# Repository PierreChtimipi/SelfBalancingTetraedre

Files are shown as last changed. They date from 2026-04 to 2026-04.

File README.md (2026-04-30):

# SelfBalancingTetraedre — Robot TétraCubli

Projet de robot auto-équilibrant en forme de tétraèdre de Reuleaux. Le robot repose sur une face, puis utilise l'élan gyroscopique d'une roue de réaction entraînée par un moteur brushless pour se redresser et maintenir sa position verticale en équilibre instable. Le projet regroupe le firmware embarqué (ESP32), des simulations MATLAB pour valider les lois de commande, et des modèles 3D pour la mécanique.

---

## Table des matières

1. [Architecture générale](#architecture-générale)
2. [Matériel utilisé](#matériel-utilisé)
3. [Configuration du projet](#configuration-du-projet)
4. [Code source (`src/`)](#code-source-src)
5. [Simulations MATLAB (`Simu_Matlab/`)](#simulations-matlab-simu_matlab)
6. [Modèles 3D (`modelisation3D/`)](#modèles-3d-modelisation3d)
7. [Configuration VSCode (`.vscode/`)](#configuration-vscode-vscode)
8. [Dépendances (`ESP32Servo`)](#dépendances-esp32servo)
9. [Artefacts de compilation (`.pio/`)](#artefacts-de-compilation-pio)

---

## Architecture générale

```
SelfBalancingTetraedre/
├── src/                    # Code source embarqué (C++)
│   ├── main.cpp
│   ├── Theorie_Proto1FaceBNO.cpp
│   ├── testCapteur.cpp
│   ├── testMoteur.cpp
│   └── testled.cpp
├── Simu_Matlab/            # Simulations de la dynamique (MATLAB)
│   ├── 2D/
│   │   ├── nominale2D.m
│   │   └── redressement2D.m
│   └── 3D/
│       ├── nominale3D.m
│       ├── redressement3D.m
│       ├── exp3.m
│       └── solution.m
├── modelisation3D/         # Fichiers de conception mécanique
│   ├── Cubli 3D.f3d
│   ├── Support moteur.3mf
│   └── Tétracubli.3mf
├── include/                # Fichiers d'en-tête partagés
├── lib/                    # Bibliothèques privées du projet
├── .vscode/                # Configuration de l'éditeur
├── platformio.ini          # Configuration de compilation PlatformIO
└── .gitignore
```

---

## Matériel utilisé

| Composant | Rôle |
|---|---|
| **ESP32** | Microcontrôleur principal (240 MHz, dual-core) |
| **MPU-6500 / MPU-9250** | IMU 6/9 axes (accéléromètre + gyroscope) via I2C |
| **BNO055** | IMU 9 axes avec fusion capteur intégrée (implémentation alternative) |
| **ESC (Electronic Speed Controller)** | Contrôleur de vitesse pour moteur brushless, commande PWM |
| **Moteur brushless** | Entraîne la roue de réaction pour le contrôle gyroscopique |
| **LEDs (GPIO 2, 4, 5)** | Indicateurs de diagnostic |

---

## Configuration du projet

### `platformio.ini`

Fichier de configuration central de PlatformIO qui définit l'environnement de compilation et de téléversement.

- **Plateforme** : `espressif32` — outillage pour microcontrôleurs Espressif ESP32
- **Carte** : `esp32doit-devkit-v1` — variante spécifique avec ses configurations de broches
- **Framework** : `arduino` — permet d'utiliser les API Arduino sur l'ESP32
- **Vitesse du moniteur série** : 115 200 bauds, standard pour la communication de débogage
- **Filtre de compilation** : seul `src/main.cpp` est compilé, pour éviter de compiler les fichiers de test lors du déploiement
- **Dépendance** : `madhephaestus/ESP32Servo @ ^3.0.5`, bibliothèque de contrôle PWM pour servos et ESC

### `.gitignore`

Exclut du suivi Git les fichiers générés automatiquement :
- Le dossier `.pio/` contenant les binaires compilés, fichiers objets et firmwares — inutile à versionner
- Les fichiers de cache IntelliSense et les configurations auto-générées de VSCode (`.vscode/c_cpp_properties.json`, `.vscode/launch.json`, `.vscode/ipch`) pour éviter des conflits entre développeurs

---

## Code source (`src/`)

### `main.cpp` — Contrôleur principal d'équilibre

Programme de production qui implémente la logique complète de redressement et d'équilibrage via une machine à états.

**Capteurs et actionneurs :**
- IMU **MPU-6500** (I2C sur GPIO 21/22 à 400 kHz) pour estimer l'angle et la vitesse angulaire
- **ESC** sur GPIO 18, commandé en PWM à 250 Hz (impulsions entre 1 000 µs et 2 000 µs)

**Algorithmes clés :**

1. **Calibration du gyroscope** : au démarrage, 200 lectures à l'arrêt permettent d'estimer le biais du gyroscope, soustrait ensuite à chaque mesure pour limiter la dérive.

2. **Calibration de la verticale** : l'utilisateur maintient le robot vertical pendant 2 secondes ; la moyenne de 50 mesures définit l'angle de référence `vertical_zero_offset_rad`.

3. **Filtre complémentaire** : fusionne les données accéléromètre (stabilité long-terme) et gyroscope (réactivité court-terme) avec un coefficient `alpha = 0.96` pour estimer l'angle `theta` en temps réel.

4. **Machine à états en 4 phases** :
   - `STATE_LYING_FLAT` : le robot est couché. Il attend que l'angle dépasse 30° puis déclenche la montée en vitesse.
   - `STATE_SPIN_UP` : montée en régime progressive sur 1,5 s, de 1 000 µs à 1 800 µs, pour accumuler l'élan gyroscopique sans à-coups.
   - `STATE_IMPULSE` : coupure instantanée de la commande moteur (1 000 µs), permettant au momentum accumulé de faire basculer le robot vers la verticale. Dure 200 ms ou jusqu'à ce que l'angle passe sous 25°.
   - `STATE_BALANCING` : équilibre actif par régulateur PD+W.

5. **Régulateur PD avec compensation de vitesse roue (PD+W)** :
   - Loi de commande : `τ = -Kp·θ - Kd·θ̇ - Kw·ω_w`
   - `Kp = 0.74` (action proportionnelle à l'angle), `Kd = 0.06` (amortissement), `Kw = 0.005` (compensation de la vitesse roue)
   - La vitesse de la roue `ω_w` est estimée par simulation (encodeur virtuel) puisqu'aucun encodeur physique n'est disponible

6. **Conversion couple → commande PWM** : le couple commandé est converti en courant via la constante moteur `Kt = 0.0095`, saturé à ±12 A, puis mappé en microsecondes pour l'ESC.

**Fréquences d'exécution** : estimation IMU à 200 Hz, boucle de commande à 100 Hz, affichage série à 10 Hz.

---

### `Theorie_Proto1FaceBNO.cpp` — Implémentation alternative avec BNO055

Implémentation alternative utilisant l'IMU **BNO055** d'Adafruit à la place du MPU-6500. Le BNO055 intègre un filtre de Kalman matériel et retourne directement des angles d'Euler fusionnés, simplifiant considérablement le code.

**Différences clés par rapport à `main.cpp` :**
- Pas de filtre complémentaire manuel : le capteur gère lui-même la fusion
- Filtre passe-bas exponentiel appliqué à l'angle de tangage (`alpha = 0.85`)
- Régulateur PD simplifié : `correction = Kp·(pitch_cible - pitch_filtré) - Kd·gyro_z` avec `Kp = 12.0`, `Kd = 5.0`
- Boucle de commande à 200 Hz, correction saturée à ±300 µs autour du point neutre 1 500 µs
- Protection contre les mesures invalides (NaN) : coupure immédiate du moteur si détectée
- ESC sur GPIO 18 à 50 Hz (au lieu de 250 Hz dans `main.cpp`)

Ce fichier représente une voie d'exploration avec un capteur plus intégré, permettant de valider si la fusion matérielle du BNO055 apporte un avantage par rapport à la fusion logicielle du MPU.

---

### `testCapteur.cpp` — Test et validation de l'IMU MPU-9250

Programme de diagnostic permettant de valider le bon fonctionnement de l'IMU et d'explorer les techniques de fusion de capteurs avant de les intégrer au contrôleur principal.

**Fonctionnement :**
- Lit le registre `WHO_AM_I` (0x75) pour identifier le capteur (codes acceptés : 0x71, 0x73, 0x70)
- Effectue une calibration sur 500 échantillons à l'arrêt, en soustrayant 1g sur l'axe Z pour isoler le biais réel
- Applique un filtre complémentaire (alpha = 0.98) pour produire des angles `angle_x` et `angle_y` stables
- Convertit les valeurs brutes 16 bits en unités physiques : accélération en g (÷ 16 384), vitesse angulaire en °/s (÷ 65,5)
- Affiche les données à 10 Hz sur la liaison série

Utile en phase de développement pour vérifier l'orientation du capteur, la qualité du signal, et régler les paramètres de filtrage avant de les transposer dans le contrôleur.

---

### `testMoteur.cpp` — Test et mise en service de l'ESC

Programme de mise en service permettant de vérifier le bon fonctionnement de l'ESC et du moteur brushless, et d'armer l'ESC de manière sécurisée.

**Séquence exécutée :**
1. Allocation des 4 timers matériels PWM de l'ESP32 via la bibliothèque ESP32PWM
2. Envoi de la commande minimale (1 000 µs) pendant 7 secondes pour l'armement de l'ESC — l'utilisateur peut connecter la batterie en toute sécurité pendant ce délai
3. Montée progressive de 1 000 µs à 1 200 µs par incréments de 5 µs toutes les 20 ms (rampe de 4 s)
4. Maintien à 1 200 µs pendant 1 s
5. Descente progressive de 1 200 µs à 1 000 µs au même rythme
6. Pause de 2 s puis répétition du cycle

Ce fichier est exclusivement un outil de développement/commission, pas une partie du firmware de production.

---

### `testled.cpp` — Test des sorties GPIO

Utilitaire minimal de validation des broches GPIO connectées à des LEDs (GPIO 2, 4, 5).

Pour chaque broche, le programme effectue alternativement des tests en logique active-haute (HIGH = LED allumée) et active-basse (LOW = LED allumée), à raison de 4 basculements de 400 ms chacun. Cela permet de vérifier les deux configurations de câblage (alimentation commune vs masse commune) et de s'assurer que le microcontrôleur contrôle bien ses sorties numériques.

---

## Simulations MATLAB (`Simu_Matlab/`)

Les simulations modélisent le tétraèdre de Reuleaux comme un **pendule inversé** et valident la faisabilité du contrôle avant implémentation matérielle. Toutes utilisent l'intégration numérique d'Euler à pas de 5 ms.

### `2D/nominale2D.m` — Stabilisation nominale 2D

Modélise une face unique du tétraèdre traitée comme un pendule inversé 2D. Paramètres : masse 0,25 kg, bras de levier 50 mm, inertie 0,003 kg·m².

Valide que le régulateur **PID** (Kp = 7, Ki = 0,3, Kd = 1,8) avec saturation du couple à ±0,08 N·m stabilise une perturbation initiale de **5°** en moins de 3 s. C'est le cas de base, le plus simple, servant de référence pour les cas plus difficiles.

### `2D/redressement2D.m` — Redressement depuis la position couchée (2D)

Simule le défi fondamental : redresser le robot depuis une position horizontale (70,5° de la verticale).

Stratégie en deux phases :
1. **Phase d'impulsion (0–500 ms)** : couple maximum constant (0,12 N·m, correspondant à la spécification EMAX réelle) pour vaincre la gravité aux grands angles
2. **Phase PID** : régulation fine une fois approché de la verticale

La simulation calcule et affiche la comparaison entre le couple gravitationnel maximum (≈ 0,70 N·m) et le couple moteur disponible, répondant à la question essentielle : **le moteur est-il suffisamment puissant ?**

### `3D/nominale3D.m` — Stabilisation nominale 3D

Identique à la version 2D mais avec les paramètres du système complet 3D : masse 0,5 kg, bras de levier 75 mm, inertie 0,06 kg·m². Les mêmes gains PID sont utilisés, validant leur généralisation à l'échelle 3D avec une perturbation initiale de 5°.

### `3D/redressement3D.m` — Redressement depuis la position couchée (3D)

**Simulation principale** du projet. Valide que le tétraèdre 3D complet (0,5 kg) peut se redresser depuis 70,5° avec le moteur disponible (0,10 N·m). Utilise la même stratégie en deux phases que la version 2D. L'inertie est volontairement réduite (0,006 kg·m²) pour les calculs aux grands angles afin d'éviter des vitesses irréalistes — phénomène bien connu en commande non-linéaire. C'est la preuve de concept centrale : si cette simulation échoue, la conception matérielle est infaisable.

### `3D/exp3.m` — Effet de la géométrie courbe (surface de Reuleaux)

Explore une caractéristique unique du tétraèdre de Reuleaux : ses faces sont **courbes**, pas planes. Quand le robot se penche sur une face courbe, le point de contact se déplace et le bras de levier effectif varie selon la relation `lb = 0,075 × cos(θ/2)`.

Cette non-linéarité géométrique supplémentaire est testée avec une perturbation initiale de 15° pour observer son effet sur la dynamique. La simulation détermine si la courbure naturelle est plutôt un avantage (réduction du couple déstabilisant) ou une complication pour le contrôle.

### `3D/solution.m` — Redressement par impulsion de roue de réaction

Simule un mécanisme alternatif de redressement : une **roue de réaction** (80 g, rayon 30 mm) tournant à 8 000 tr/min est brusquement freinée, transférant son moment cinétique au corps du robot pour initier le redressement.

La quantité de mouvement angulaire transférée génère une vitesse initiale calculée, affichée en console ("Vitesse de remontée générée par le choc"). Après ce transfert impulsionnel, le régulateur PID prend le relais pour maintenir l'équilibre. Cette approche s'inspire des systèmes de contrôle d'attitude des satellites. La simulation révèle que l'impulsion générée reste modeste à cette échelle, faisant du couple moteur continu le mécanisme principal de redressement.

---

## Modèles 3D (`modelisation3D/`)

### `Cubli 3D.f3d`

Fichier Fusion 360 (`.f3d`) contenant la conception CAO paramétrique complète du robot. Permet de modifier les dimensions, vérifier les assemblages, réaliser des analyses d'interférence, et préparer les exports pour la fabrication.

### `Support moteur.3mf`

Fichier d'impression 3D (format `.3mf`) pour la pièce de fixation du moteur. Ce support assure le positionnement précis et rigide du moteur brushless dans le tétraèdre. Le format `.3mf` (successeur du STL) inclut les informations de couleur, matériau et orientation d'impression.

### `Tétracubli.3mf`

Fichier d'impression 3D pour le corps principal du robot. Contient la géométrie du tétraèdre de Reuleaux avec ses faces caractéristiques courbées, conçu pour être imprimé puis assemblé avec les composants électroniques et mécaniques.

---

## Configuration VSCode (`.vscode/`)

### `c_cpp_properties.json`

Configuration auto-générée par PlatformIO pour l'IntelliSense C++ de VSCode. Définit plus de 240 chemins d'inclusion couvrant l'intégralité du framework Arduino, les bibliothèques ESP32 IDF (FreeRTOS, SPI, I2C, Bluetooth, réseau), et les dépendances du projet. Configure le compilateur Xtensa GCC, les standards C99/C++11 avec extensions GNU, et les macros de préprocesseur (`F_CPU = 240000000L`, `ARDUINO_ARCH_ESP32`, etc.). Permet l'autocomplétion et la navigation dans tout le code framework directement dans l'éditeur.

### `extensions.json`

Recommande l'extension **PlatformIO IDE** (`platformio.platformio-ide`) et déconseille explicitement le pack C++ de Microsoft (`ms-vscode.cpptools-extension-pack`) qui entrerait en conflit avec la gestion IntelliSense de PlatformIO. Assure un environnement cohérent pour tous les développeurs du projet.

### `launch.json`

Fournit trois configurations de débogage matériel via OpenOCD :
- **PIO Debug** : compilation puis débogage (workflow standard)
- **PIO Debug (skip Pre-Debug)** : débogage sans recompilation (itération rapide)
- **PIO Debug (without uploading)** : débogage sans réécriture du firmware (debug à distance ou firmware déjà en place)

### `settings.json`

Désactive les soulignements d'erreur rouge (`C_Cpp.errorSquiggles = "disabled"`) pour éviter les doublons entre l'analyseur PlatformIO et celui de Microsoft CppTools.

---

## Dépendances (`ESP32Servo`)

La bibliothèque **ESP32Servo v3.1.3** (installée automatiquement dans `.pio/libdeps/`) fournit le contrôle PWM précis nécessaire pour commander l'ESC.

**Caractéristiques clés :**
- Utilise le périphérique **LEDC** (LED Control) de l'ESP32 pour générer des signaux PWM par hardware — beaucoup plus précis qu'une solution logicielle
- 16 canaux PWM disponibles sur l'ESP32 standard
- Supporte les commandes en microsecondes directes avec résolution 16 bits
- Plage de commande : 500–2 500 µs
- Allocation automatique des ressources hardware, sans configuration manuelle des timers

Dans ce projet, elle est utilisée exclusivement pour contrôler l'ESC du moteur brushless via des impulsions PWM calibrées (1 000–2 000 µs).

---

## Artefacts de compilation (`.pio/`)

Répertoire auto-généré par PlatformIO, non versionné (exclu par `.gitignore`).

- **`.pio/build/esp32doit-devkit-v1/`** : contient `firmware.bin` (image à flasher sur l'ESP32), `firmware.elf` (avec symboles de débogage), `firmware.map` (carte mémoire), `bootloader.bin`, `partitions.bin`, et tous les fichiers objets intermédiaires
- **`.pio/libdeps/esp32doit-devkit-v1/`** : dépendances téléchargées et compilées automatiquement (ESP32Servo)
- **`idedata.json`** : données d'environnement exportées vers VSCode pour alimenter l'IntelliSense

Ces fichiers sont régénérés à chaque compilation et ne doivent pas être modifiés manuellement.

---

## Démarrage rapide

1. Installer [PlatformIO](https://platformio.org/) via l'extension VSCode
2. Ouvrir le dossier du projet — PlatformIO détecte `platformio.ini` automatiquement
3. Brancher l'ESP32 en USB
4. Compiler et téléverser avec le bouton **Upload** de PlatformIO (ou `pio run -t upload`)
5. Ouvrir le moniteur série à 115 200 bauds pour suivre le démarrage et la calibration
6. Maintenir le robot vertical pendant 2 s lors de la phase de calibration initiale

Pour tester les composants individuellement, modifier temporairement `build_src_filter` dans `platformio.ini` pour cibler `testCapteur.cpp`, `testMoteur.cpp`, ou `testled.cpp`.

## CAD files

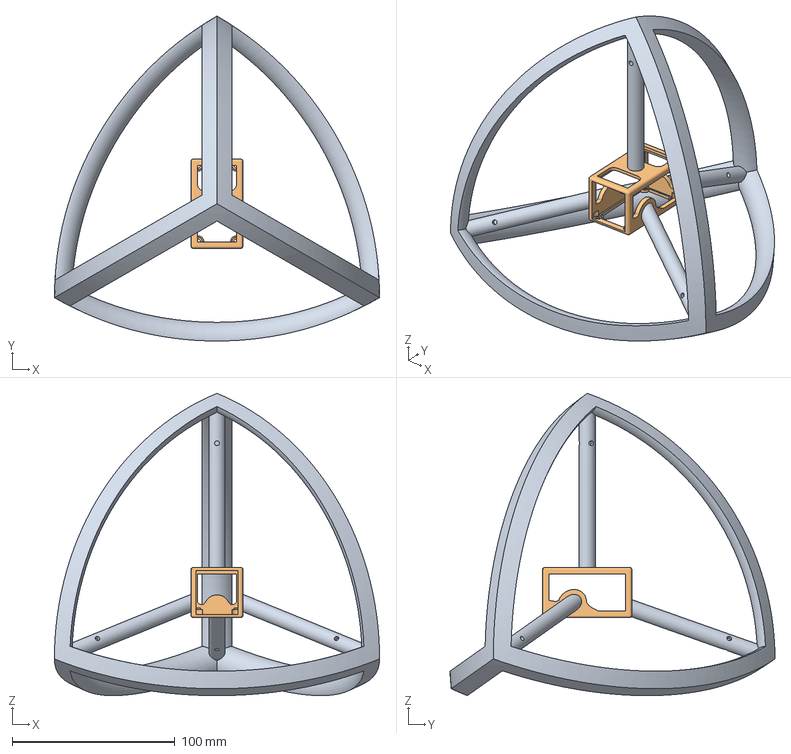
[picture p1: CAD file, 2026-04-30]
modelisation3D/Tétracubli.3mf
200.0 x 199.9 x 185.9 mm
Structure Releau
StructureLipo

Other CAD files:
modelisation3D/Support moteur.3mf
modelisation3D/Cubli 3D.f3d

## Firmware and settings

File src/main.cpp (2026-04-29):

#include <Arduino.h>
#include <Wire.h>
#include <ESP32Servo.h>
#include <math.h>

// =========================================================
// Configuration Matérielle
// =========================================================
#define PIN_SDA 21
#define PIN_SCL 22
const int ESC_PIN = 18;
#define MPU_ADDR 0x68

Servo esc;

// =========================================================
// Paramètres
// =========================================================
const float Kp = 0.74f;
const float Kd = 0.06f;
const float Kw = 0.005f;
const float Kt = 0.0095f;   
const float IQ_MAX = 12.0f; 

const unsigned long DT_EST_US = 5000;  // 200 Hz
const unsigned long DT_CTL_US = 10000; // 100 Hz

// =========================================================
// Variables Globales
// =========================================================
float theta_est = 0.0f;
float theta_dot_est = 0.0f;
float theta = 0.0f;
float theta_dot = 0.0f;
float omega_w = 0.0f;

float vertical_zero_offset_rad = 0.0f; 
float gx_offset = 0, gy_offset = 0, gz_offset = 0; // On ne calibre que le Gyro pour éviter les bugs de gravité

unsigned long last_est_us = 0;
unsigned long last_ctl_us = 0;

enum RobotState {
    STATE_LYING_FLAT, 
    STATE_SPIN_UP,    
    STATE_IMPULSE,    
    STATE_BALANCING   
};

RobotState currentState = STATE_LYING_FLAT;
unsigned long state_timer = 0;

// =========================================================
// Outils
// =========================================================
float clamp(float value, float vmin, float vmax) {
    if (value < vmin) return vmin;
    if (value > vmax) return vmax;
    return value;
}

// =========================================================
// MPU-6500 : Lecture I2C
// =========================================================
void mpu_write(uint8_t reg, uint8_t val) {
    Wire.beginTransmission(MPU_ADDR);
    Wire.write(reg);
    Wire.write(val);
    Wire.endTransmission();
}

void mpu_read_accel_gyro(float &ax, float &ay, float &az, float &gx, float &gy, float &gz) {
    Wire.beginTransmission(MPU_ADDR);
    Wire.write(0x3B);
    Wire.endTransmission(false);
    Wire.requestFrom((uint16_t)MPU_ADDR, (uint8_t)14, (uint8_t)true);
    
    int16_t raw_ax = Wire.read()<<8 | Wire.read();
    int16_t raw_ay = Wire.read()<<8 | Wire.read();
    int16_t raw_az = Wire.read()<<8 | Wire.read();
    Wire.read(); Wire.read(); // Température ignorée
    int16_t raw_gx = Wire.read()<<8 | Wire.read();
    int16_t raw_gy = Wire.read()<<8 | Wire.read();
    int16_t raw_gz = Wire.read()<<8 | Wire.read();

    // Conversion en g (sans offset pour l'accéléromètre pour préserver la vraie norme)
    ax = raw_ax / 16384.0f;
    ay = raw_ay / 16384.0f;
    az = raw_az / 16384.0f;
    
    // Gyro avec offsets
    gx = ((raw_gx - gx_offset) / 65.5f) * (M_PI / 180.0f);
    gy = ((raw_gy - gy_offset) / 65.5f) * (M_PI / 180.0f);
    gz = ((raw_gz - gz_offset) / 65.5f) * (M_PI / 180.0f);
}

void init_angle_from_acc(float ax, float ay, float az) {
    theta_est = atan2f(ax, ay); // Axe Y supposé vertical
}

void estimate_angle(float ax, float ay, float az, float gyro_z_rad_s, float dt_s, float alpha=0.96f) {
    float theta_gyro = theta_est + gyro_z_rad_s * dt_s;
    float theta_acc = atan2f(ax, ay);
    
    float norm = sqrtf(ax * ax + ay * ay + az * az);
    // Tolérance large pour s'assurer que le filtre corrige bien la dérive
    if (norm > 0.5f && norm < 1.5f) {
        theta_est = alpha * theta_gyro + (1.0f - alpha) * theta_acc;
    } else {
        theta_est = theta_gyro;
    }
    theta_dot_est = gyro_z_rad_s;
}

// =========================================================
// Encodeur Virtuel
// =========================================================
float estimated_omega_w = 0.0f; 
void update_virtual_encoder(float commanded_torque, float dt) {
    estimated_omega_w += (commanded_torque / 0.001f) * dt;
    estimated_omega_w *= 0.99f;
    estimated_omega_w = clamp(estimated_omega_w, -500.0f, 500.0f);
}

// =========================================================
// SETUP
// =========================================================
void setup() {
    Serial.begin(115200);
    Wire.begin(PIN_SDA, PIN_SCL);
    Wire.setClock(400000);

    mpu_write(0x6B, 0x01); 
    mpu_write(0x1B, 0x08); 
    mpu_write(0x1C, 0x00); 
    mpu_write(0x1A, 0x03); 

    ESP32PWM::allocateTimer(0);
    esc.setPeriodHertz(250); 
    esc.attach(ESC_PIN, 1000, 2000);
    esc.writeMicroseconds(1000); // ARMEMEMT A 0 GAZ
    
    Serial.println("ÉTAPE 1 : NE BOUGEZ PAS (Posé à plat ou debout) ! Calibration du Gyro...");
    long sgx=0, sgy=0, sgz=0;
    for (int i = 0; i < 200; i++) {
        Wire.beginTransmission(MPU_ADDR);
        Wire.write(0x43); // Registre direct du gyro
        Wire.endTransmission(false);
        Wire.requestFrom((uint16_t)MPU_ADDR, (uint8_t)6, (uint8_t)true);
        sgx += (int16_t)(Wire.read()<<8 | Wire.read());
        sgy += (int16_t)(Wire.read()<<8 | Wire.read());
        sgz += (int16_t)(Wire.read()<<8 | Wire.read());
        delay(5);
    }
    gx_offset = sgx/200.0f; gy_offset = sgy/200.0f; gz_offset = sgz/200.0f;

    Serial.println("\nÉTAPE 2 : CALIBRATION DU ZERO VERTICAL !");
    Serial.println("-> MAINTENEZ LE ROBOT DEBOUT EN PARFAIT ÉQUILIBRE PENDANT 2 SECONDES...");
    delay(2000);
    
    float sum_angle = 0;
    for(int i=0; i<50; i++) {
        float ax, ay, az, gx, gy, gz;
        mpu_read_accel_gyro(ax, ay, az, gx, gy, gz);
        sum_angle += atan2f(ax, ay);
        delay(10);
    }
    vertical_zero_offset_rad = sum_angle / 50.0f;
    
    float ax, ay, az, gx, gy, gz;
    mpu_read_accel_gyro(ax, ay, az, gx, gy, gz);
    init_angle_from_acc(ax, ay, az);

    Serial.println("\n✅ PRÊT ! Posez le robot sur la table. L'ESC a dû biper son armement.");
    last_est_us = micros();
    last_ctl_us = last_est_us;
}

// =========================================================
// LOOP Principale
// =========================================================
void loop() {
    unsigned long now_us = micros();
    int current_pwm = 1000; 

    // --- Boucle IMU (200 Hz) ---
    if ((now_us - last_est_us) >= DT_EST_US) {
        float dt_est = (now_us - last_est_us) / 1000000.0f;
        last_est_us = now_us;

        float ax, ay, az, gx, gy, gz;
        mpu_read_accel_gyro(ax, ay, az, gx, gy, gz);
        estimate_angle(ax, ay, az, gz, dt_est, 0.96f);
        
        theta = theta_est - vertical_zero_offset_rad;
        theta_dot = theta_dot_est;
    }

    // --- Boucle Commande (100 Hz) ---
    if ((now_us - last_ctl_us) >= DT_CTL_US) {
        float dt_ctl = (now_us - last_ctl_us) / 1000000.0f; 
        last_ctl_us = now_us;
        float angle_deg = theta * (180.0f / M_PI);

        switch (currentState) {
            
            case STATE_LYING_FLAT:
                current_pwm = 1000; // Arrêt
                // S'il est couché (angle > 30°)
                if (fabs(angle_deg) > 30.0f) { 
                    if (millis() - state_timer > 2000) {
                        currentState = STATE_SPIN_UP;
                        state_timer = millis();
                        Serial.println("⚡ SPIN-UP : Accélération progressive...");
                    }
                } else {
                    state_timer = millis(); 
                }
                break;

            case STATE_SPIN_UP:
                {
                    unsigned long elapsed = millis() - state_timer;
                    if (elapsed < 1500) {
                        // Accélération en douceur (Soft-Start) pour ne pas bloquer l'ESC
                        // On passe de 1000 à 1800 sur 1.5 secondes
                        current_pwm = 1000 + (int)((elapsed * 800) / 1500);
                    } else {
                        currentState = STATE_IMPULSE;
                        state_timer = millis();
                        Serial.println("💥 KICK ! Freinage brutal !");
                    }
                }
                break;

            case STATE_IMPULSE:
                current_pwm = 1000; // Coupure des gaz

                // On laisse l'inertie lever le robot. S'il se redresse un peu, on passe en équilibre.
                if (millis() - state_timer > 200 || fabs(angle_deg) < 25.0f) {
                    currentState = STATE_BALANCING;
                    Serial.println("🎯 TENTATIVE D'ÉQUILIBRE !");
                }
                break;

            case STATE_BALANCING:
                if (fabs(angle_deg) > 40.0f) {
                    currentState = STATE_LYING_FLAT;
                    state_timer = millis();
                    Serial.println("❌ CRASH : Retour au sol.");
                    break;
                }

                float tau_cmd = -Kp * theta - Kd * theta_dot - Kw * estimated_omega_w;
                update_virtual_encoder(tau_cmd, dt_ctl);

                float iq_cmd = clamp(tau_cmd / Kt, -IQ_MAX, IQ_MAX);
                // Le moteur ne tourne qu'en marche avant (1000 à 2000)
                current_pwm = 1000 + (int)((iq_cmd / IQ_MAX) * 1000.0f);
                current_pwm = clamp(current_pwm, 1000, 2000); 
                break;
        }

        esc.writeMicroseconds(current_pwm);
    }
    
    // --- Affichage (10 Hz) ---
    static unsigned long last_print = 0;
    if (millis() - last_print > 100) {
        last_print = millis();
        float angle_deg = theta * (180.0f / M_PI);
        String etat_str = (currentState == STATE_LYING_FLAT) ? "COUCHÉ" : 
                          (currentState == STATE_SPIN_UP) ? "ÉLAN" : 
                          (currentState == STATE_IMPULSE) ? "KICK" : "ÉQUILIBRE";
        Serial.printf("[%s] Angle: %+6.1f° | PWM: %4d\n", etat_str.c_str(), angle_deg, esc.readMicroseconds());
    }
}

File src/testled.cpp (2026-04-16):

#include <Arduino.h>

const int LED_PINS[] = {2, 4, 5};
const size_t LED_PIN_COUNT = sizeof(LED_PINS) / sizeof(LED_PINS[0]);
const int BLINK_MS = 400;

void setup() {
    Serial.begin(115200);
    delay(300);
    Serial.println("Test LED ESP32 (pins 2, 4, 5)");
}

void loop() {
    for (size_t i = 0; i < LED_PIN_COUNT; i++) {
        int pin = LED_PINS[i];
        pinMode(pin, OUTPUT);

        // Test actif HIGH (HIGH allume, LOW eteint)
        Serial.printf("GPIO %d - test actif HIGH\n", pin);
        for (int n = 0; n < 4; n++) {
            digitalWrite(pin, HIGH);
            delay(BLINK_MS);
            digitalWrite(pin, LOW);
            delay(BLINK_MS);
        }
        delay(400);

        // Test actif LOW (LOW allume, HIGH eteint)
        Serial.printf("GPIO %d - test actif LOW\n", pin);
        for (int n = 0; n < 4; n++) {
            digitalWrite(pin, LOW);
            delay(BLINK_MS);
            digitalWrite(pin, HIGH);
            delay(BLINK_MS);
        }

        // Etat neutre
        digitalWrite(pin, LOW);
        delay(800);
    }

    Serial.println("Cycle termine, reprise...");
}

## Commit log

2026-04-16 feat: ajout de nouveaux fichiers pour le contrôle du moteur et des tests de capteur, mise à jour de la configuration du projet
2026-04-21 feat: ajout de la logique de contrôle du moteur et mise à jour des paramètres de configuration
2026-04-27 spin up wheel, tetra going up
2026-04-29 feat: Add new experiments for 2D and 3D stabilization
    - Implemented redressement2D.m for full 2D stabilization with PID control.
    - Created exp3.m to simulate instability with Reuleaux geometry.
    - Added nominale3D.m for nominal stabilization with a small angle perturbation.
    - Developed redressement3D.m for realistic 3D redressing from 70.5° to 0°.
    - Introduced solution.m for swing-up stabilization using initial momentum.
    - Removed outdated image files and unnecessary source files.
    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
2026-04-30 feat: Ajout de la documentation et des fichiers de modélisation 3D pour le robot tétraèdre auto-équilibrant
    [Cubli 3D.f3d, Support moteur.3mf, Tétracubli.3mf]
